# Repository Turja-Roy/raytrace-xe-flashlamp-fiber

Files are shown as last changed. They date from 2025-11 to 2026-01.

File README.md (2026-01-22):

# VUV Flashlamp-to-Fiber Coupling Optimization

A comprehensive ray tracing and optimization framework for designing two-lens optical systems that efficiently couple vacuum ultraviolet (VUV) light from xenon flashlamp sources into optical fibers.

## Table of Contents

- [Project Overview](#project-overview)
  - [Key Results](#key-results)
- [Features](#features)
  - [Six Optimization Algorithms](#six-optimization-algorithms)
  - [Multi-Objective Optimization](#multi-objective-optimization)
  - [Additional Capabilities](#additional-capabilities)
- [Performance](#performance)
  - [Vectorized Ray Tracing](#vectorized-ray-tracing)
  - [Benchmark Your System](#benchmark-your-system)
- [Database Storage](#database-storage)
  - [Two-Database Architecture](#two-database-architecture)
  - [Managing the Lens Database](#managing-the-lens-database)
  - [SQLite Backend for Results](#sqlite-backend-for-results)
- [Web Dashboard](#web-dashboard)
  - [Starting the Dashboard](#starting-the-dashboard)
  - [Features](#features-1)
  - [Usage Examples](#usage-examples)
  - [API Endpoints](#api-endpoints)
- [Installation](#installation)
  - [Requirements](#requirements)
  - [Quick Start](#quick-start)
- [Configuration Files](#configuration-files)
  - [Using Preset Profiles](#using-preset-profiles)
  - [Using Custom Configuration Files](#custom-configuration)
- [Usage Guide](#usage-guide)
  - [Basic Commands](#basic-commands)
  - [Command Reference](#command-reference)
- [File Structure](#file-structure)
- [Output Files](#output-files)
  - [Results CSVs](#results-csvs)
  - [Plot Files](#plot-files)
  - [Log Files](#log-files)
- [Physics and Implementation](#physics-and-implementation)
  - [Ray Tracing](#ray-tracing)
  - [Atmospheric Absorption](#atmospheric-absorption)
  - [Multi-Objective Optimization](#multi-objective-optimization-1)
- [Performance Recommendations](#performance-recommendations)
- [Example Workflows](#example-workflows)
- [Troubleshooting](#troubleshooting)
- [Technical Background](#technical-background)
  - [Research Context](#research-context)
  - [Physical Constants](#physical-constants)
  - [Optimization Implementation](#optimization-implementation)
<!-- - [Citation](#citation) -->
- [Author](#author)
- [Contributing](#contributing)

## Project Overview

This project addresses the challenge of efficiently collecting 220nm light from a xenon flashlamp arc source and coupling it into a small-core optical fiber. The system uses:

- **Source**: 60W Xenon flash lamp with 3mm diameter arc in water-cooled jacket
- **Geometry**: Cooling jacket with 26mm optical path length limits beam divergence to 22.85°
- **Target**: 1mm core optical fiber with NA=0.22 and acceptance angle of 24.8°
- **Approach**: Two-lens plano-convex system optimization via deterministic ray tracing
- **Physics**: Full geometric optics with atmospheric O₂ absorption modeling, geometric losses from cooling jacket vignetting (43% transmission)

> **📄 Technical Report**: For complete analysis, physical modeling details, and validated experimental design, see [`doc/technical_report.pdf`](doc/technical_report.pdf). The report documents the optimized LA4148+LA4022 configuration achieving 24% coupling in air and 26-27% in argon at 220nm.

### Key Results

- **Coupling Efficiency**: 24-27% achievable with optimized configurations under current geometry constraints (Air: 24%, Argon: 26-27% at 220nm)
- **System Length**: ~70mm for optimized configurations (e.g., LA4148+LA4022)
- **Atmospheric Impact**: 8-10% coupling improvement in argon vs. air due to eliminated O₂ absorption at 220nm
- **Medium Dependence**: Argon shows significantly better performance than air due to lack of UV absorption
- **Constraint Impact**: Cooling jacket geometry (lenses must be positioned ≥27mm from source) significantly constrains optimization space

#### Best Known Configuration

**Lens Pair**: LA4148 (f=50.2mm) + LA4022 (f=60mm)
- **Air Performance**: η = 0.24 (24%), L ≈ 70mm
- **Argon Performance**: η = 0.26-0.27 (26-27%), L ≈ 70mm
- **Positions**: z₁ ≈ 27mm (cooling jacket constraint), z₂ ≈ 34mm
- **Physical Implementation**: ThorLabs SM1 optomechanics (see `Assembly/` directory)

This configuration is validated through multiple optimization methods and documented in `doc/technical_report.pdf`.

## Features

### Seven Optimization Algorithms

| Method | Speed | Convergence | Best For |
|---|---|---|---|
| **Paraxial** ⚡⚡ | ~7ms | Fast screening | **Ultra-fast initial screening of thousands of combinations** |
| **Powell** ⚡ | ~0.1-0.2s | Good | **Quick optimization, everyday use** |
| **Nelder-Mead** ⚡ | ~0.1-0.2s | Good | **Fast local search** |
| Grid Search | ~0.2-0.3s | Systematic | Baseline comparison, small grids |
| Differential Evolution | ~1-2s | Excellent | Thorough global search when time permits |
| Bayesian | ~2-3s | Excellent | Sample-efficient exploration |
| Dual Annealing | ~4-5s | Excellent | Escaping local minima |

*Timings are per lens pair with 1000 rays using vectorized tracing on typical hardware. Paraxial uses analytical approximation (no ray tracing).*

**⚠️ Important Note on Paraxial Approximation**: The paraxial screening mode uses thin/thick lens equations with ABCD matrix propagation for ultra-fast evaluation (~20,503 combinations in ~3 minutes). However, it has known limitations:
- **Grid search limitations**: Uses coarse 5×5×5 grid (125 samples per pair) which may miss optimal configurations
- **Spacing assumptions**: Assumes lenses should be separated by ≥0.5× focal length, but optimal configurations may have much closer spacing
- **Best use case**: Initial screening to identify promising candidates, followed by full ray-trace optimization
- **Not a replacement**: Should be used to guide full optimization, not replace it

### Multi-Objective Optimization

Balance coupling efficiency against system compactness using the alpha parameter:

```
objective = α × (1 - coupling) + (1 - α) × (normalized_length)
```

- **α = 0.9**: Maximize coupling (90% weight) - laboratory setups
- **α = 0.7**: Balanced (default) - general purpose
- **α = 0.5**: Equal priority - compact designs

### Additional Capabilities

- **Paraxial Approximation**: Ultra-fast screening of all 20,503 lens combinations in ~3 minutes using analytical approximations
- **Tolerance Analysis**: Assess manufacturing sensitivity to longitudinal displacements (single-pair and batch modes)
- **Wavelength Analysis**: Study coupling efficiency across 180-300nm range
- **Web Dashboard**: Interactive browser-based results viewer with filtering and plotting
- **Medium Selection**: Air, argon, or helium propagation
- **Resume Support**: Automatic checkpoint/resume for interrupted batch runs
- **Rich Visualization**: Ray trace diagrams, spot diagrams, wavelength plots, tolerance curves
- **Batch Processing**: Automatic splitting and parallel processing of large lens catalogs
- **Dual Database Architecture**: Separate lens catalog (202 lenses) and optimization results databases

## Performance

### Vectorized Ray Tracing

The codebase uses **vectorized NumPy operations** for ray tracing, achieving **10-15x speedup** over serial implementations:

- **1,000 rays**: ~12ms (vectorized) vs ~120ms (serial) ⚡
- **10,000 rays**: ~19ms (vectorized) vs ~287ms (serial) ⚡

All optimization algorithms automatically use vectorized tracing. To disable (for debugging):

```yaml
# In your config file
rays:
  use_vectorized: false  # Default: true
```

**Implementation details**:
- Batch processing of all rays simultaneously using NumPy broadcasting
- Vectorized ray-sphere intersections, refraction calculations, and transmission factors
- Boolean masks to track ray success/failure through optical pipeline
- Located in `scripts/raytrace_helpers_vectorized.py`

### Benchmark Your System

```bash
python test_vectorization.py --rays 5000 --trials 5
```

Expected output:
```
Serial time:     0.045 ± 0.010 s
Vectorized time: 0.003 ± 0.001 s
Speedup:         13.9x
```

## Database Storage

The system uses two SQLite databases:
- **Lens catalog** (`data/lenses.db`): 202 lenses from ThorLabs and Edmund Optics
- **Optimization results** (`results/optimization.db`): Stores run metadata and results

### Managing Lenses

```bash
# Import lenses from CSV
python raytrace.py import-lenses

# List available lenses
python raytrace.py list-lenses --use-database

# Add new lenses
python -m scripts.add_lenses_from_csv new_lenses.csv --format thorlabs
```

### Querying Results

Enable database storage in `configs/default.yaml`:
```yaml
database:
  enabled: true
  path: ./results/optimization.db
```

Common queries:
```bash
# Show all runs
python -m scripts.db_query list-runs

# Find best results
python -m scripts.db_query best --limit 20 --min-coupling 0.20

# Export specific run
python -m scripts.db_query export-run 2025-10-24_coupling_0_21_air output.csv
```

## Web Dashboard

Interactive browser-based interface for viewing, filtering, and analyzing optimization results.

### Starting the Dashboard

```bash
# Auto-detect database or use CSV files
python raytrace.py dashboard

# Custom port
python raytrace.py dashboard --port 8080

# Specify database file
python raytrace.py dashboard --db results/integration_test.db

# Using config file
python raytrace.py dashboard --config my_config.yaml

# Config with CLI override
python raytrace.py dashboard --config my_config.yaml --port 5000
```

**Config file example** (`my_config.yaml`):
```yaml
dashboard:
  port: 8080
  db_path: results/optimization.db
  auto_open: false  # Future feature
```

The dashboard will start a local web server and display:
```
Dashboard running at http://localhost:5000
Press Ctrl+C to stop
```

Open the URL in your browser to access the interface.

### Features

**Statistics Overview**:
- Total optimization results
- Number of runs
- Best coupling efficiency achieved
- Average coupling across all results

**Interactive Filtering**:
- Filter by coupling efficiency range (min/max)
- Filter by medium (air, argon, helium)
- Filter by specific lens pairs
- Export filtered results as CSV

**Data Visualization**:
- Results table with sorting (click column headers)
- Coupling efficiency distribution histogram
- Lens pair comparison plots (compare different optimization methods)

**Data Sources**:
- Automatically reads from SQLite database if available
- Falls back to CSV files in `results/` directory
- Scans all subdirectories for optimization results
- Skips tolerance and wavelength analysis files

### Usage Examples

```bash
# View results from a specific database
python raytrace.py dashboard --db results/optimization.db

# Run on a different port (e.g., if 5000 is in use)
python raytrace.py dashboard --port 8888

# View CSV results without database
python raytrace.py dashboard  # Auto-detects and loads CSV files
```

## Installation

### Requirements

- Python 3.7+
- Required packages:
  ```bash
  pip install numpy scipy pandas matplotlib tqdm regex flask
  ```
- Optional (for Bayesian optimization):
  ```bash
  pip install scikit-optimize
  ```
- Optional (for web dashboard):
  ```bash
  pip install flask
  ```
  *Note: Flask is included in the required packages above*

### Quick Start

```bash
git clone <repository>
cd raytrace-xe-flashlamp-fiber
python raytrace.py particular LA4001 LA4647 --opt powell
```

## Configuration Files

All modes support YAML configuration files for parameter management. CLI arguments override config values.

### Using Preset Profiles

```bash
# Quick test (100 rays, Powell, fast)
python raytrace.py particular LA4001 LA4647 --profile quick_test

# Argon batch (1000 rays, differential evolution)
python raytrace.py combine --profile argon_batch

# Tolerance test (5000 rays, 41 samples, ±1mm)
python raytrace.py tolerance LA4001 LA4647 --profile tolerance_test
```

Available profiles in `configs/`: `quick_test`, `argon_batch`, `wavelength_study`, `tolerance_test`, `integration_test`

### Custom Configuration

Create `my_config.yaml`:

```yaml
rays:
  n_rays: 1500

medium:
  type: argon

optimization:
  method: powell

analyze:
  coupling_threshold: 0.22
  methods: [differential_evolution, powell]
```

Use it:
```bash
python raytrace.py particular LA4001 LA4647 --config my_config.yaml

# CLI overrides config
python raytrace.py particular LA4001 LA4647 --config my_config.yaml --medium air
```

See `configs/default.yaml` for all available options.

## Usage Guide

### Basic Commands

#### Screen All Lens Combinations with Paraxial Approximation (Ultra-Fast)

```bash
# Screen all 20,503 combinations in ~3 minutes (requires --use-database)
python raytrace.py paraxial --use-database --medium argon

# Results are filtered to coupling ≥ 1% and sorted by predicted coupling
# Outputs CSV with top candidates for full ray-trace optimization
```

**Note**: Paraxial approximation provides fast screening but has limitations (see warnings in Features section). Use results to guide full optimization, not as final values.

**Recommended workflow:**
```bash
# 1. Fast paraxial screening
python raytrace.py paraxial --use-database --medium argon

# 2. Review top candidates
head -20 results/paraxial_2025-11-19_argon/paraxial_results_2025-11-19.csv

# 3. Full optimization on top candidates
python raytrace.py particular 84-281 89-414 --opt differential_evolution --medium argon
```

#### Optimize a Specific Lens Pair (Recommended Starting Point)

```bash
# Fast optimization with Powell's method (recommended)
python raytrace.py particular LA4001 LA4647 --opt powell

# Thorough optimization with differential evolution (slower but more thorough)
python raytrace.py particular LA4001 LA4647 --opt differential_evolution

# Try in argon (no UV absorption)
python raytrace.py particular LA4001 LA4647 --opt powell --medium argon
```

#### Optimize All Combinations

```bash
# Strategic scan with pre-selected L1/L2 candidates (924 combinations, recommended)
python raytrace.py select --opt powell

# Exhaustive scan of all possible combinations (24,336 combinations)
python raytrace.py combine --opt powell

# Prioritize coupling efficiency (90% weight)
python raytrace.py select --opt powell --alpha 0.9

# Prioritize compact systems (50/50 weight)
python raytrace.py select --opt powell --alpha 0.5
```

**Select vs Combine modes:**
- **select**: Tests 21 L1 candidates × 44 L2 candidates = 924 strategically chosen lens pairs
- **combine**: Tests all 156 lenses × 156 lenses = 24,336 possible combinations (26× more)
- **Recommendation**: Use `select` for efficient exploration; use `combine` only when exhaustive search is needed

#### Compare All Methods

```bash
# Test all 6 optimization methods on a single lens pair
python raytrace.py compare LA4001 LA4647
```

This runs all available methods and reports:
- Coupling efficiency achieved
- Total system length
- Computation time
- Best method recommendation

#### Resume Interrupted Batch Runs

```bash
# Resume from checkpoint
python raytrace.py combine --opt powell continue 2025-10-14
```

#### Analyze High-Coupling Results

Re-optimize promising results with multiple methods to find absolute best configurations.

```bash
# CLI-only usage
python raytrace.py analyze \
  --results-file results/2025-10-17/results_combine_*.csv \
  --coupling-threshold 0.20

# Using config file to specify methods and parameters
python raytrace.py analyze \
  --config my_config.yaml \
  --results-file results/2025-10-17/results_combine_*.csv

# Config with CLI override
python raytrace.py analyze \
  --config my_config.yaml \
  --results-file results/2025-10-17/results_combine_*.csv \
  --coupling-threshold 0.18 \
  --n-rays 2000
```

**Config file example** (`my_config.yaml`):
```yaml
analyze:
  n_rays: 1000
  coupling_threshold: 0.22
  methods:
    - differential_evolution
    - dual_annealing
    - powell
```

The `methods` list controls which optimizers to test on each lens pair. Results are saved separately for each method and combined into a single best-of-all file.

#### Wavelength Dependence Analysis

Study how coupling varies with wavelength.

```bash
# CLI-only usage
python raytrace.py wavelength-analyze \
  --results-file results/2025-10-17/36-681+LA4647.csv \
  --wl-start 180 --wl-end 300 --wl-step 10

# Using config file
python raytrace.py wavelength-analyze \
  --config my_config.yaml \
  --results-file results/2025-10-17/36-681+LA4647.csv

# Config with CLI override for wavelength range
python raytrace.py wavelength-analyze \
  --config my_config.yaml \
  --results-file results/2025-10-17/36-681+LA4647.csv \
  --wl-start 190 --wl-end 210 --wl-step 2
```

**Config file example** (`my_config.yaml`):
```yaml
wavelength:
  wl_start: 180
  wl_end: 300
  wl_step: 10
  n_rays: 2000
  methods:
    - differential_evolution
    - powell
```

The `methods` list controls which optimizers calibrate the geometry at 220nm before wavelength sweeping.

**Plotting results:**
```bash
# Generate plots from wavelength analysis
python raytrace.py wavelength-analyze-plot \
  --results-dir results/wavelength_analyze_2025-10-18

# With polynomial curve fitting
python raytrace.py wavelength-analyze-plot \
  --results-dir results/wavelength_analyze_2025-10-18 \
  --fit polynomial

# Aggregated plots with error bars
python raytrace.py wavelength-analyze-plot \
  --results-dir results/wavelength_analyze_2025-10-18 \
  --aggregate
```

#### Tolerance Analysis

Assess manufacturing sensitivity by analyzing how coupling efficiency varies with small displacements in lens positions.

##### Single Lens Pair Mode

```bash
# Analyze tolerance for a specific lens pair
python raytrace.py tolerance LA4001 LA4647 --opt powell

# Use high-resolution tolerance profile from config
python raytrace.py tolerance LA4001 LA4647 --profile tolerance_test

# Custom tolerance parameters
python raytrace.py tolerance LA4001 LA4647 \
  --z-range 1.0 \
  --n-samples 41 \
  --n-rays 5000

# Test in argon environment
python raytrace.py tolerance LA4001 LA4647 --opt powell --medium argon
```

##### Batch Mode

Analyze tolerance for multiple lens pairs from optimization results:

```bash
# Batch tolerance analysis on high-coupling results
python raytrace.py tolerance \
  --results-file results/2025-11-07_combine_powell_argon/batch_combine_1.csv \
  --coupling-threshold 0.35 \
  --z-range 1.0 \
  --n-samples 41 \
  --n-rays 5000 \
  --medium argon \
  --use-database

# Use config file with defaults (results_file and coupling_threshold from config)
python raytrace.py tolerance --profile tolerance_test --use-database

# Or override specific config values via CLI
python raytrace.py tolerance \
  --profile tolerance_test \
  --coupling-threshold 0.35 \
  --use-database
```

**Batch mode benefits:**
- Test tolerance on multiple optimized configurations at once
- Compare tolerance characteristics across different lens pairs
- Identify most manufacturable designs (highest tolerance to misalignment)
- Uses pre-optimized positions from results file (no re-optimization needed)

**What it does**:
- First optimizes the lens pair to find best configuration
- Systematically perturbs each lens position (z_l1, z_l2) independently
- Measures coupling efficiency at each position
- Generates tolerance curves showing sensitivity to misalignment

**Output files (single-pair mode)**:
- `tolerance_L1_<lens1>+<lens2>.csv` - L1 position sweep data
- `tolerance_L2_<lens1>+<lens2>.csv` - L2 position sweep data
- `tolerance_summary_<lens1>+<lens2>.csv` - Summary statistics
- `tolerance_<lens1>+<lens2>.png` - Tolerance curve plot

**Output files (batch mode)**:
- `tolerance_L1_<lens1>+<lens2>.csv` - L1 sweep data for each pair
- `tolerance_L2_<lens1>+<lens2>.csv` - L2 sweep data for each pair
- `tolerance_summary_<lens1>+<lens2>.csv` - Individual pair summary
- `tolerance_batch_summary.csv` - Comparison across all pairs
- `tolerance_batch_comparison.png` - Bar chart comparing all configurations

**Configuration options** (in YAML config files):
```yaml
tolerance:
  z_range_mm: 1.0      # ±1.0mm range around optimal position
  n_samples: 41        # Number of positions to test (41 = 0.05mm steps)
  n_rays: 5000         # Rays per position (higher = more accurate)

batch_tolerance:
  results_file: results/combine_*/batch_combine_1.csv  # Results CSV for batch mode
  coupling_threshold: 0.35    # Minimum coupling to include in batch analysis
```

**Interpreting results**:
- Steep slopes indicate high sensitivity to that lens position
- Flat regions indicate tolerance to small displacements
- Asymmetric curves reveal directional sensitivity
- Use results to set manufacturing tolerances

**Example workflow**:
```bash
# 1. Find best configuration
python raytrace.py particular LA4001 LA4647 --opt differential_evolution

# 2. Analyze tolerance with high resolution
python raytrace.py tolerance LA4001 LA4647 --profile tolerance_test

# 3. Review tolerance curves
ls plots/*tolerance*/tolerance_LA4001+LA4647.png

# 4. Check numerical results
cat results/*tolerance*/tolerance_summary_LA4001+LA4647.csv
```

### Command Reference

```
Commands:
  particular <lens1> <lens2>    Optimize specific lens pair
  compare <lens1> <lens2>       Compare all optimization methods
  select                        Optimize L1×L2 candidate combinations (924 pairs, recommended)
  combine                       Optimize all lens combinations (24,336 pairs, exhaustive)
  paraxial                      Ultra-fast screening of all 20,503 combinations using analytical approximation (~3min)
  analyze                       Re-analyze high-coupling results
  wavelength-analyze            Study wavelength dependence
  wavelength-analyze-plot       Create plots from wavelength data
  tolerance <lens1> <lens2>     Analyze manufacturing tolerance sensitivity
  dashboard                     Start interactive web dashboard
  import-lenses                 Import lenses from CSV files into database
  list-lenses                   List available lenses from database or CSV

Options:
  --opt <method>                Optimization method (default: powell)
                                Options: powell, nelder_mead, grid_search,
                                         differential_evolution, bayesian,
                                         dual_annealing
  --alpha <0-1>                 Coupling vs. length trade-off (default: 0.7)
  --medium <type>               Propagation medium (default: air)
                                Options: air, argon, helium
  --n-rays <count>              Number of rays per trace (default: 1000)
  --wl-start <nm>               Wavelength analysis start (default: 180)
  --wl-end <nm>                 Wavelength analysis end (default: 300)
  --wl-step <nm>                Wavelength analysis step (default: 10)
  --z-range <mm>                Tolerance analysis range (default: 0.5)
  --n-samples <count>           Tolerance analysis samples (default: 21)
  --coupling-threshold <value>  Minimum coupling for analyze mode
  --results-file <path>         Input CSV file for analyze/wavelength modes
  --results-dir <path>          Results directory for plotting
  --fit <type>                  Curve fit type: polynomial, spline
  --aggregate                   Generate aggregated plots with error bars
  --port <number>               Dashboard port (default: 5000)
  --db <path>                   Database file for dashboard
  --profile <name>              Use preset configuration profile
  --config <path>               Use custom YAML configuration file
  continue                      Resume incomplete batch run
  <YYYY-MM-DD>                  Specify run date for continue mode
```

## File Structure

```
raytrace-xe-flashlamp-fiber/
├── raytrace.py                    # Main entry point
│
├── scripts/
│   ├── optimization/              # Optimization algorithms
│   │   ├── __init__.py
│   │   ├── powell.py              # Powell's method (fast)
│   │   ├── nelder_mead.py         # Nelder-Mead simplex (fast)
│   │   ├── grid_search.py         # Systematic grid search
│   │   ├── differential_evolution.py  # Global optimizer (thorough)
│   │   ├── bayesian.py            # Bayesian optimization
│   │   ├── dual_annealing.py      # Simulated annealing
│   │   ├── optimization_runner.py # Unified interface
│   │   └── fiber_position_optimizer.py  # Fiber position optimization helper
│   │
│   ├── analysis.py                # Analysis and wavelength studies
│   ├── Aspheric.py                # Aspheric lens class
│   ├── BiConvex.py                # Bi-convex lens class
│   ├── calcs.py                   # Physics calculations (refraction, absorption)
│   ├── cli.py                     # Command-line interface
│   ├── config_loader.py           # YAML configuration file handler
│   ├── consts.py                  # Physical constants and system parameters
│   ├── data_io.py                 # File I/O and result management
│   ├── database.py                # SQLite database backend (optimization results)
│   ├── db_query.py                # Database query CLI
│   ├── hitran_data.py             # HITRAN absorption data handling
│   ├── lens_database.py           # Lens catalog database management
│   ├── lens_factory.py            # Lens object factory
│   ├── paraxial_approximation.py  # Ultra-fast paraxial screening (~7ms/pair)
│   ├── PlanoConvex.py             # Plano-convex lens class
│   ├── raytrace_helpers.py        # Core ray tracing functions
│   ├── raytrace_helpers_vectorized.py  # Vectorized ray tracing (10-15x faster)
│   ├── runner.py                  # Batch processing and continuation
│   ├── tolerance_analysis.py      # Manufacturing tolerance testing
│   ├── visualizers.py             # Plotting and visualization
│   └── web_dashboard.py           # Flask-based interactive web dashboard
│
├── configs/                       # YAML configuration files
│   ├── default.yaml               # Default parameters
│   ├── quick_test.yaml            # Fast testing profile
│   ├── argon_batch.yaml           # Argon medium batch profile
│   ├── wavelength_study.yaml      # Wavelength analysis profile
│   ├── tolerance_test.yaml        # High-resolution tolerance profile
│   └── integration_test.yaml      # Database integration testing
│
├── data/                          # Lens catalogs
│   ├── lenses.db                  # SQLite lens catalog database (202 lenses)
│   ├── Combined_Lenses.csv        # Full lens catalog CSV (legacy, 156 lenses)
│   ├── l1_candidates.csv          # Candidate L1 lenses
│   ├── l1_candidates_ext.csv      # Extended L1 candidates
│   ├── l2_candidates.csv          # Candidate L2 lenses
│   ├── l2_candidates_ext.csv      # Extended L2 candidates
│   └── *.csv, *.xlsx              # Vendor lens data (ThorLabs, Edmund Optics)
│
├── results/                       # Output directory
│   ├── <run_id>/                  # Results organized by run ID
│   │   ├── batch_*.csv            # Intermediate batch results
│   │   ├── results_*.csv          # Final combined results
│   │   ├── tolerance_*.csv        # Tolerance analysis data
│   │   └── temp_*.json            # Checkpoint files
│   └── *.db                       # SQLite database files
│
├── plots/                         # Generated plots
│   └── <run_id>/
│       ├── C-<coupling>_L1-*_L2-*.png      # Ray trace diagrams
│       ├── spot_*.png                       # Spot diagrams
│       ├── tolerance_*.png                  # Tolerance curves
│       └── wavelength_analyze_*/            # Wavelength analysis plots
│
├── logs/                          # Execution logs
│   └── *.log                      # Detailed execution logs
│
├── Assembly/                      # CAD models and mechanical design
│   ├── Assembly.FCStd             # FreeCAD assembly file (LA4148+LA4022)
│   ├── List.md                    # Parts list (ThorLabs SM1 components)
│   └── *.step                     # Individual component STEP files
│
└── doc/                           # Documentation
    ├── technical_report.pdf       # Full technical report
    ├── images/                    # Figures and plots for report
    └── *.tex, *.bib               # LaTeX source files
```

## Output Files

### Results CSVs

All optimization results are saved as CSV files with columns:

- `lens1`, `lens2`: Lens identifiers
- `f1_mm`, `f2_mm`: Focal lengths (mm)
- `z_l1`, `z_l2`, `z_fiber`: Positions along optical axis (mm)
- `total_len_mm`: Total system length (mm)
- `coupling`: Coupling efficiency (0-1)

Example: `results/2025-10-18_combine_powell_air/results_combine_2025-10-18.csv`

### Plot Files

#### Ray Trace Diagrams
Shows full ray paths through the optical system with lens positions and fiber location.

Filename format: `C-<coupling>_L1-<lens1>_L2-<lens2>.png`

#### Spot Diagrams
Shows ray impact positions at the fiber face, indicating coupling quality.

Filename format: `spot_C-<coupling>_L1-<lens1>_L2-<lens2>.png`

#### Wavelength Analysis Plots
- Per-lens plots: Coupling vs. wavelength for each lens combination
- Per-method plots: Comparing all lens pairs for each optimization method
- Aggregated plots: Mean curves with error bars across multiple runs

### Log Files

Detailed execution logs including:
- Timestamp for each optimization
- Method being used
- Coupling efficiency and system length
- Computation time
- Error messages and warnings

Example: `logs/2025-10-18_combine_powell_air.log`

## Physics and Implementation

Uses deterministic ray tracing with atmospheric absorption modeling (O₂ absorption in air). Multi-objective optimization balances coupling efficiency against system length using the `alpha` parameter. See `doc/technical_report.pdf` for detailed physics and implementation.

## Performance Recommendations

### For Ultra-Fast Initial Screening
**Use Paraxial Approximation** - Screen all 20,503 combinations in ~3 minutes:
```bash
python raytrace.py paraxial --use-database --medium argon
# Then full ray-trace on top candidates
```

### For Everyday Use
**Use Powell's method** - Fast and reliable:
```bash
python raytrace.py combine --opt powell
```

### For Best Possible Results
**Use Differential Evolution** - Slower but more thorough:
```bash
python raytrace.py combine --opt differential_evolution
```

### For Method Comparison
**Use compare mode** - Test all methods on a sample:
```bash
python raytrace.py compare LA4001 LA4647
```

### For Large Catalogs (Recommended Workflow)
**Multi-stage approach for best results**:
```bash
# Stage 1: Ultra-fast paraxial screening (~3 min for all 20,503 pairs)
python raytrace.py paraxial --use-database --medium argon

# Stage 2: Fast ray-trace on top 100 from paraxial (~10 min with Powell)
# Extract top lens pairs from paraxial results, then:
python raytrace.py particular <lens1> <lens2> --opt powell --medium argon

# Stage 3: Thorough optimization on top 20 (~3-5 min with DE)
python raytrace.py particular <lens1> <lens2> --opt differential_evolution --medium argon

# Total time: ~15-20 minutes vs. ~8 hours for full DE on all pairs
```

### Alternative: Traditional Approach (No Paraxial)
**Start with Powell, verify with DE**:
```bash
# 1. Fast scan with Powell (~40 min for all 24,336 pairs)
python raytrace.py combine --opt powell

# 2. Re-optimize top candidates with differential evolution
python raytrace.py analyze \
  --results-file results/2025-10-18/results_*.csv \
  --coupling-threshold 0.20 \
  --opt differential_evolution
```

## Example Workflows

### Workflow 1: Ultra-Fast Screening with Paraxial Approximation

**Best for**: Quickly identifying promising lens pairs from full catalog

```bash
# Step 1: Fast paraxial screening of all 20,503 combinations (~3 minutes)
python raytrace.py paraxial --use-database --medium argon

# Step 2: Review top candidates
head -30 results/paraxial_2025-11-19_argon/paraxial_results_2025-11-19.csv

# Step 3: Full ray-trace optimization on top 10 candidates
# Example: Top result is 84-281 + 89-414 with predicted 35.5% coupling
python raytrace.py particular 84-281 89-414 --opt differential_evolution --medium argon

# Step 4: Batch optimize multiple promising pairs
for pair in "84-281 89-414" "48-278 LA4194" "84-282 89-411"; do
    python raytrace.py particular $pair --opt differential_evolution --medium argon
done

# Step 5: Compare results
grep "Coupling=" logs/particular_*_differential_evolution_argon.log

# Step 6: Tolerance analysis on best performer
python raytrace.py tolerance 84-281 89-414 --profile tolerance_test --medium argon
```

**Important Notes**:
- Paraxial provides screening only - actual coupling may differ significantly
- Some lens pairs may perform better than paraxial predicts (e.g., if optimal spacing is closer than paraxial assumes)
- Always validate with full ray tracing before finalizing design

### Workflow 2: Find Best Lens Pair for Maximum Coupling

```bash
# Step 1: Quick scan prioritizing coupling
python raytrace.py combine --opt powell --alpha 0.9

# Step 2: Re-optimize top candidates thoroughly
python raytrace.py analyze \
  --results-file results/2025-10-18_combine_powell_air/results_combine_2025-10-18.csv \
  --coupling-threshold 0.22

# Step 3: View results interactively
python raytrace.py dashboard
```

### Workflow 3: Manufacturing Tolerance Assessment

```bash
# Step 1: Optimize a promising lens pair
python raytrace.py particular LA4001 LA4647 --opt differential_evolution

# Step 2: Run high-resolution tolerance analysis
python raytrace.py tolerance LA4001 LA4647 --profile tolerance_test

# Step 3: View tolerance curves
ls plots/2025-10-24_None_powell_air/tolerance_LA4001+LA4647.png

# Step 4: Check tolerance summary statistics
cat results/2025-10-24_None_powell_air/tolerance_summary_LA4001+LA4647.csv

# Step 5: Compare tolerances in different media
python raytrace.py tolerance LA4001 LA4647 --opt powell --medium argon \
  --z-range 1.0 --n-samples 41
```

### Workflow 4: Interactive Results Analysis with Dashboard

```bash
# Step 1: Run batch optimization with database enabled
# (Ensure database.enabled: true in configs/default.yaml)
python raytrace.py select --opt powell --alpha 0.9

# Step 2: Start the dashboard with config
python raytrace.py dashboard --config dashboard_config.yaml

# Step 3: Open browser to http://localhost:8080 (or configured port)
# - Filter results by coupling > 0.22
# - View coupling distribution histogram
# - Compare different lens pairs
# - Export filtered results as CSV

# Alternative: Use CSV files directly (no database)
python raytrace.py dashboard  # Auto-detects CSV files

# Step 4: Export high-performing results via API
curl "http://localhost:8080/api/export?min_coupling=0.22" -o best_results.csv
```

**dashboard_config.yaml:**
```yaml
dashboard:
  port: 8080
  db_path: results/optimization.db
```

## Troubleshooting

### Slow Performance

**Problem**: Optimization takes too long  
**Solutions**:
- Use Powell or Nelder-Mead instead of Differential Evolution
- Reduce number of rays: `--n-rays 500`
- Process specific lens pairs instead of full catalog

### Poor Coupling Results

**Problem**: Low coupling efficiency  
**Solutions**:
- Try different optimization method: `--opt differential_evolution`
- Increase alpha to prioritize coupling: `--alpha 0.9`
- Verify lens data in `data/Combined_Lenses.csv`
- Check if lenses are physically compatible

### Import Errors

**Problem**: `ModuleNotFoundError: No module named 'skopt'`  
**Solution**: Install scikit-optimize or use different method:
```bash
pip install scikit-optimize
# OR
python raytrace.py combine --opt powell
```

### Interrupted Batch Runs

**Problem**: Run stopped midway through catalog  
**Solution**: Resume from checkpoint:
```bash
python raytrace.py combine --opt powell continue 2025-10-18
```

### Memory Issues

**Problem**: Out of memory with large catalogs  
**Solutions**:
- Batch processing is automatic for >100 combinations
- Reduce rays per trace: `--n-rays 500`
- Process smaller subsets using `particular` mode

### Paraxial Results Don't Match Full Ray Tracing

**Problem**: Lens pair performs well in full ray tracing but missing or poor in paraxial results  
**Root Causes**:
1. **Grid search limitations**: Paraxial uses 5×5×5 coarse grid (125 samples) which may miss optimal positions
2. **Conservative spacing assumptions**: Assumes z_l2 ≥ z_l1 + tc + 0.5×f1, but optimal may be much closer
3. **Same-lens pairs**: May require tighter spacing than paraxial grid searches

**Example**: Some lens pairs like 48-274 + 48-274 perform well in full ray tracing (z_l1=27mm, z_l2=33mm) but paraxial predicts <1% because the grid doesn't search close lens spacing (e.g., z_l2 < 58mm). The current best configuration LA4148+LA4022 achieves 24-27% coupling and was identified through systematic full ray-trace optimization.

**Solutions**:
- Use paraxial for initial screening only, not final values
- Always validate promising pairs with full ray-trace optimization
- For specific pairs of interest, run full optimization directly with `particular` mode
- Consider paraxial results as conservative lower bounds

**Recommended workflow**: Paraxial screening → Full optimization of top 20-50 candidates → Tolerance analysis of best results

## Technical Background

This project optimizes two-lens optical systems for coupling 220nm VUV light from xenon flashlamps into optical fibers. For research context, physical constants, optimization algorithms, and implementation details, see `doc/technical_report.pdf`.

<!-- ## Citation -->
<!---->
<!-- If you use this code in your research, please cite: -->
<!---->
<!-- ``` -->
<!-- Turja Roy, "Optimization of Two-Lens Coupling Systems for VUV Flashlamp  -->
<!-- to Fiber Applications Using Ray Tracing and Multi-Algorithm Comparison", -->
<!-- University of Texas at Arlington (2025) -->
<!-- ``` -->
<!---->
<!-- Technical report: `doc/technical_report.pdf` -->

## Author

**Turja Roy**  
Department of Physics  
University of Texas at Arlington

## Contributing

For questions, issues, or contributions, please contact the author or open an issue in the repository.

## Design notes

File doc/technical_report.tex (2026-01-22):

\input{preamble.tex}
\usepackage{bm}

\title{\large\bfseries
    A Modular Ray Tracing Framework for Optimizing VUV Flashlamp-to-Fiber Coupling Systems
}

\author{Turja Roy, Dr. Jonathan Abraham Asaadi, Dr. Varghese Anto Chirayath}
\affil{Department of Physics, University of Texas at Arlington, Arlington, TX 76019, USA}
\date{}

\begin{document}

\twocolumn[
\begin{@twocolumnfalse}
    \maketitle

    \begin{abstract}
        A comprehensive ray tracing methodology is presented for optimizing two-lens coupling systems for vacuum ultraviolet (VUV) flashlamp-to-fiber applications with realistic experimental constraints. The system couples 220 nm light from a Hamamatsu L7685 60W xenon flashlamp (3 mm arc) with E6611 cooling jacket into a 1 mm fiber core (NA = 0.22). The cooling jacket imposes critical geometric constraints: lens positioning constrained to z $\geq$ 27 mm and angular acceptance limited to 22.85$^\circ$, introducing 43\% geometric vignetting loss. Six optimization algorithms---grid search, Powell's method, differential evolution, Nelder-Mead simplex, dual annealing, and Bayesian optimization---are systematically compared using deterministic ray tracing with atmospheric absorption modeling. Systematic analysis identifies optimal configurations achieving coupling efficiencies up to 0.27 (argon) and 0.24 (air) at 220 nm, representing realistic performance under cooling jacket constraints. Powell's method and Nelder-Mead emerge as recommended algorithms for routine optimization, providing rapid convergence (~0.5--1 s per lens pair) and reliable performance. Combined atmospheric oxygen absorption and extended path lengths (optical system $L \approx$ 70 mm) create measurable medium-dependent effects at 220 nm: systematic comparison reveals 8--10\% coupling improvement in argon versus air for the LA4148+LA4022 configuration, closely matching the predicted 8.1\% atmospheric absorption loss and validating the attenuation model. This indicates air propagation is viable when the performance penalty is acceptable, while argon maximizes coupling. Wavelength dependence analysis (150--300 nm) establishes chromatic performance characteristics and validates wavelength-dependent material modeling. The framework provides both a practical design tool incorporating realistic experimental constraints and methodological insights for non-convex optical optimization problems.
    \end{abstract}
    \vspace{0.5cm}
\end{@twocolumnfalse}
]

\section{Introduction}

Efficient coupling of vacuum ultraviolet light from incoherent sources into optical fibers presents significant challenges due to the inherent divergence of arc lamp sources and the limited acceptance angles of fibers \cite{hecht2017}. The Hamamatsu L7685 60W xenon flash lamp provides a compact broadband source (190--2000 nm) suitable for liquid argon purity monitoring applications in the VUV/DUV range. This work focuses on optimizing coupling at the design wavelength of 220 nm, where fiber-optic delivery enables remote sensing and flexible optical system configurations in cryogenic environments.

The design of compact coupling optics requires balancing multiple objectives: maximizing coupling efficiency, minimizing physical length, and maintaining practical manufacturability with commercially available optical components. Traditional lens design approaches often rely on paraxial approximations or specialized optical design software \cite{greivenkamp2004}. However, the large numerical aperture and wide divergence angles in Xe flashlamp systems necessitate full ray tracing to accurately predict system performance.

In this work, a stratified ray tracing framework is developed that incorporates realistic source geometry, lens specifications, fiber acceptance criteria, and atmospheric absorption effects (O$_2$, N$_2$, and H$_2$O). The design problem is formulated as a multi-objective optimization task, and six distinct optimization algorithms are systematically compared to identify lens positioning that maximizes performance. This approach provides both a practical design tool and insights into the efficacy of various optimization strategies for optical systems with complex, non-convex objective functions characterized by multiple local optima and discrete ray-counting mechanics that preclude
 analytical gradient computation.

\section{System Description}

\subsection{Optical Configuration}

The optical system comprises a Hamamatsu L7685 60W xenon flash lamp \cite{hamamatsu} with Hamamatsu E6611 cooling jacket, two fused silica lenses, and a multi-mode optical fiber \cite{accuglass} arranged along a common optical axis. The lamp emits broadband radiation (190--2000 nm) from a compact 3.0 mm diameter arc; this work analyzes coupling performance at $\lambda =$ 150--300 nm. 

The lamp assembly includes a protective Single Crystal Sapphire Glass window (14.3 mm diameter) positioned 8.7 mm from the arc. Critically, the Hamamatsu E6611 cooling jacket surrounds the lamp housing and constrains the optical aperture through its M23 threaded exit port (inner diameter 23 mm) located approximately 26 mm from the arc center. This cooling jacket imposes both geometric constraints on lens positioning and vignetting losses on the emitted light, as detailed in Section 2.2. The two-lens relay system is positioned after the cooling jacket exit to collect and refocus the divergent light into the fiber.

% FIGURE 1: Lamp and Cooling Jacket Dimensional Outline
\begin{figure}[htpb]
    \centering
    \begin{subfigure}{0.45\textwidth}
        \centering
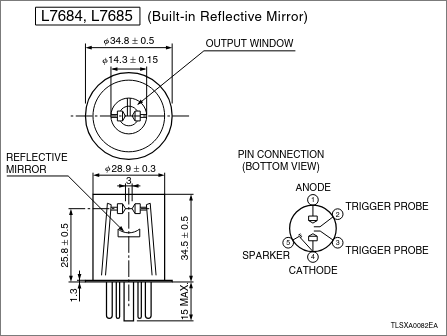
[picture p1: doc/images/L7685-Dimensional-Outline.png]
        
        \caption{}
    \end{subfigure}
    \begin{subfigure}{0.45\textwidth}
        \centering
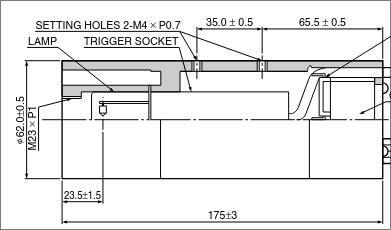
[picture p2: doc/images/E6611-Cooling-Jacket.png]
        
        \caption{}
    \end{subfigure}
    \caption{Dimensional Outline of (a) Hamamatsu L7685 Xenon Flash Lamp and (b) Hamamatsu E6611 Cooling Jacket (Unit: mm)}
    \label{fig:lamp_outline}
\end{figure}

\subsection{Source Characteristics}

The xenon arc source exhibits a spatially extended emission profile with angular divergence constrained by the cooling jacket geometry. The source is modeled as emitting rays from a circular disk of radius $r_{\text{arc}} = 1.5$ mm with angular distribution characterized by a maximum half-angle $\theta_{\max} = 22.85^\circ$, determined by the cooling jacket aperture geometry: $\theta_{\max} = \arctan(r_{\text{jacket}}/z_{\text{jacket}}) = \arctan(11.5\text{ mm}/26\text{ mm})$, where $r_{\text{jacket}} = 11.5$ mm is the cooling jacket M23 thread radius and $z_{\text{jacket}} = 26$ mm is the distance from arc to jacket exit.

This coherent beam model assumes that rays originating at radius $r$ from the arc center propagate with half-angle $\theta(r) = \theta_{\max} \cdot r/r_{\text{arc}}$, representing the geometric constraint imposed by the cooling jacket aperture. The cooling jacket introduces a geometric loss factor of approximately 0.43 (43\% vignetting loss, 57\% transmission) due to solid angle reduction compared to an unobstructed hemispherical emission. This vignetting represents a fundamental constraint on system performance that cannot be eliminated through optical design optimization.

\subsection{Fiber Specifications}

The target optical fiber features a 1.0 mm core diameter with numerical aperture NA $= 0.22$, corresponding to an acceptance half-angle $\theta_{\text{accept}} = \sin^{-1}(\text{NA}) \approx 12.4^\circ$. Successful coupling requires that incident rays satisfy both spatial (impinge within the core area) and angular (arrive within the acceptance cone) criteria simultaneously.

\subsection{Lens Properties}

All lenses are fabricated from UV-grade fused silica with refractive index $n = 1.528$ at $\lambda = 220$ nm, calculated using the Sellmeier dispersion formula \cite{malitson1965}. Plano-convex, bi-convex, and aspheric lens geometries are tested for their favorable aberration characteristics and commercial availability. Specifications including focal length $f$, radius of curvature $R$, center thickness $t_c$, edge thickness $t_e$, and clear aperture diameter are drawn from manufacturer catalogs \cite{thorlabs,edmundoptics}.

\section{Computational Methods}

\subsection{Stratified Ray Sampling}

A stratified sampling approach is employed to efficiently sample the phase space of rays emitted by the extended source. For each simulation, $N = 1000$ to 2000 rays are generated with origins uniformly distributed over the arc area and directions following the prescribed angular distribution.

Radial positions are sampled using inverse transform sampling to ensure uniform spatial distribution:
\begin{align}
r_i &= \sqrt{U_i} \cdot r_{\text{arc}}, \quad U_i \sim \mathcal{U}(0,1) \\
\phi_i &= \frac{2\pi i}{N}
\end{align}
where $\mathcal{U}(0,1)$ denotes the uniform distribution. Azimuthal angles $\phi_i$ are uniformly spaced to provide comprehensive angular coverage. The Cartesian coordinates of source points are:
\begin{equation}
\mathbf{o}_i = (r_i \cos\phi_i, \, r_i \sin\phi_i, \, 0)
\end{equation}

The ray propagation half-angle scales linearly with radial position:
\begin{equation}
\theta_i = \theta_{\max} \cdot \frac{r_i}{r_{\text{arc}}}
\end{equation}
resulting in direction vectors:
\begin{equation}
\mathbf{d}_i = (\sin\theta_i \cos\phi_i, \, \sin\theta_i \sin\phi_i, \, \cos\theta_i)
\end{equation}
All direction vectors are normalized to unit length.

\subsection{Geometric Ray Tracing}

Ray propagation through the optical system is computed using vector-based geometric optics without paraxial approximations \cite{glassner1989}. This approach accurately accounts for large ray angles, finite apertures, and aberrations.

\subsubsection{Ray-Surface Intersection}

For a spherical surface of radius $R$ centered at $\mathbf{c}$, the intersection of ray $\mathbf{p}(t) = \mathbf{o} + t\mathbf{d}$ is found by solving:
\begin{equation}
\|\mathbf{o} + t\mathbf{d} - \mathbf{c}\|^2 = R^2
\end{equation}
Expanding yields the quadratic equation:
\begin{align}
a &= 1 \\
b &= 2(\mathbf{o} - \mathbf{c}) \cdot \mathbf{d} \\
c &= \|\mathbf{o} - \mathbf{c}\|^2 - R^2 \\
\Delta &= b^2 - 4c
\end{align}
The nearest positive intersection occurs at:
\begin{equation}
t = \frac{-b - \sqrt{\Delta}}{2}, \quad \Delta \geq 0
\end{equation}
Rays missing the surface ($\Delta < 0$) or blocked by the aperture ($\sqrt{p_x^2 + p_y^2} > r_{\text{ap}}$) are rejected.

\subsubsection{Vector Refraction}

At each refractive interface, Snell's law is applied in vector form. For incident ray $\mathbf{d}_{\text{in}}$, surface normal $\mathbf{n}$ (pointing into the incident medium), and refractive indices $n_1$ and $n_2$:
\begin{align}
\eta &= \frac{n_1}{n_2} \\
\cos\theta_i &= -\mathbf{n} \cdot \mathbf{d}_{\text{in}} \\
k &= 1 - \eta^2(1 - \cos^2\theta_i)
\end{align}
Total internal reflection occurs when $k < 0$. Otherwise, the refracted ray is:
\begin{equation}
\mathbf{d}_{\text{out}} = \eta \mathbf{d}_{\text{in}} + (\eta \cos\theta_i - \sqrt{k})\mathbf{n}
\end{equation}
For spherical surfaces, the outward normal is $\mathbf{n} = (\mathbf{p} - \mathbf{c})/R$. For planar surfaces, $\mathbf{n} = (0, 0, -1)$. Bi-convex lenses have two spherical surfaces, while aspheric lenses require polynomial surface normals computed from their aspheric profile.

% FIGURE 2: Ray Tracing Visualization (2D System Diagram)
\begin{figure}[htpb]
    \centering
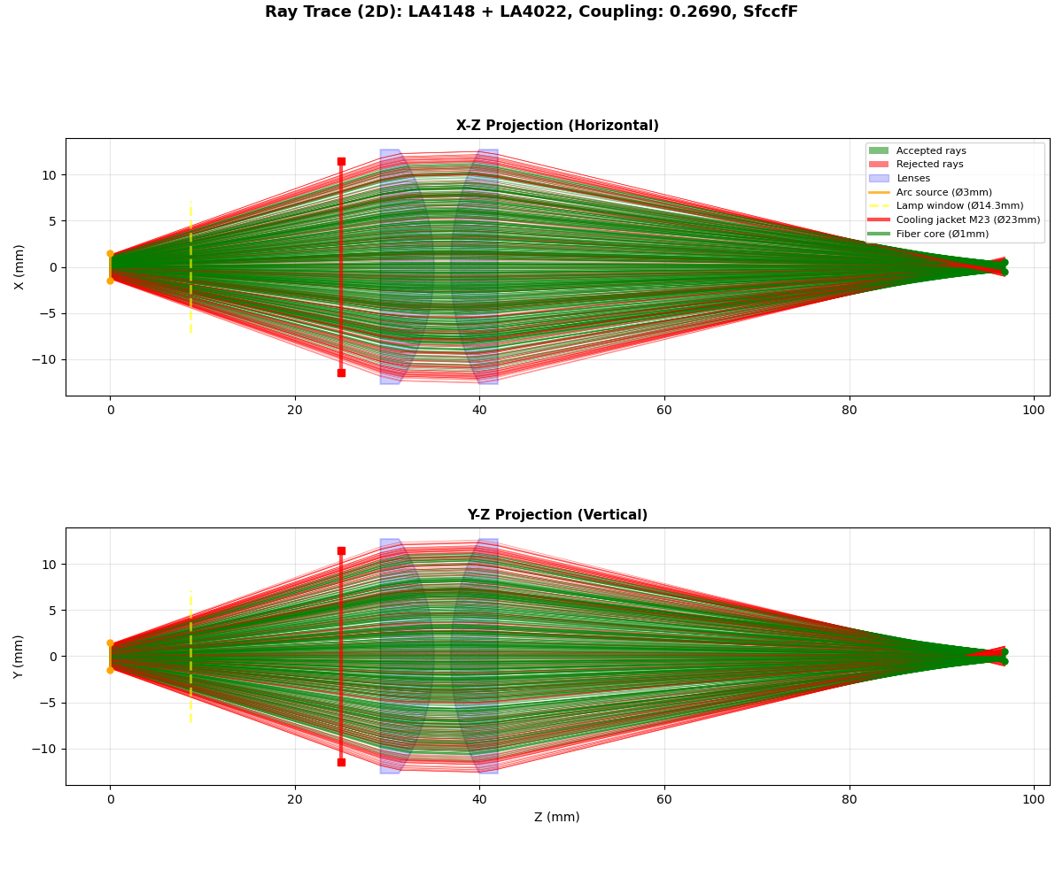
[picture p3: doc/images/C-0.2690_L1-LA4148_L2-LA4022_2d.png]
    
    \caption{Ray trace diagram showing the optimal optical system layout at 220 nm in argon: xenon arc source (left), two plano-convex lenses (LA4148 and LA4022, $f_1 = 50.2$ mm, $f_2 = 60$ mm), and fiber entrance (right). Ray paths illustrate beam collection and refocusing through the two-lens relay system under cooling jacket constraints (first lens positioned at z $\geq$ 27 mm). Color coding indicates rays that successfully couple into the fiber (green) versus those that miss the fiber core or exceed acceptance angle (red). This configuration achieves coupling efficiency $\eta = 0.27$ with system length $L \approx 70$ mm.}
    \label{fig:raytrace_2d}
\end{figure}

\subsubsection{Lens Propagation}

After refraction at the front surface, the ray propagates through the lens material to the back surface. The exit point is determined by tracing the refracted ray to its intersection with the back surface geometry:

\textbf{Plano-convex lenses:} If the back surface is planar (located at $z = z_{\text{back}}$), the intersection is computed as:
\begin{equation}
\mathbf{o}_{\text{back}} = \mathbf{p}_{\text{front}} + \frac{z_{\text{back}} - p_{\text{front},z}}{d_{\text{refracted},z}} \mathbf{d}_{\text{refracted}}
\end{equation}

\textbf{Bi-convex lenses:} Both surfaces are spherical. The back surface has center of curvature $\mathbf{c}_{\text{back}}$ and radius $R_{\text{back}}$. The ray-sphere intersection equation (Eq.~5--8) is applied with the refracted ray origin $\mathbf{o} = \mathbf{p}_{\text{front}}$ and direction $\mathbf{d} = \mathbf{d}_{\text{refracted}}$.

\textbf{Aspheric lenses:} The back surface may be planar, spherical convex, or spherical concave. The appropriate intersection method is selected based on the back surface type. In the current implementation, aspheric front surfaces are approximated as spherical with base radius $R_{\text{front}}$ (conic constant $k=0$); full aspheric ray tracing with polynomial surface equations is reserved for future enhancement when complete aspheric coefficients become available.

All methods compute the actual optical path through the lens based on the refracted ray direction and lens geometry, accounting for ray angle and radial position effects.

\subsection{Fiber Coupling Analysis}

After traversing both lenses, rays propagate to the fiber face located at $z = z_{\text{fiber}}$. The intersection point is computed as:
\begin{equation}
\mathbf{p}_{\text{fiber}} = \mathbf{o}_2 + \frac{z_{\text{fiber}} - o_{2z}}{d_{2z}} \mathbf{d}_2
\end{equation}
where $\mathbf{o}_2$ and $\mathbf{d}_2$ are the ray origin and direction after the second lens.

A ray successfully couples into the fiber if:
\begin{enumerate}[leftmargin=*]
    \item \textit{Spatial criterion}: $\sqrt{p_x^2 + p_y^2} \leq r_{\text{core}} = 0.5$ mm
    \item \textit{Angular criterion}: $\theta = \arccos(|d_{2z}|/\|\mathbf{d}_2\|) \leq \theta_{\text{accept}} = 12.4^\circ$
\end{enumerate}
The coupling efficiency is:
\begin{equation}
\eta_{\text{coupling}} = \frac{N_{\text{accepted}}}{N_{\text{total}}}
\end{equation}

\section{Optimization Framework}

\subsection{Problem Formulation}

The optical design task is formulated as a constrained multi-objective optimization problem. Given a pair of lenses with fixed optical properties (focal lengths $f_1$ and $f_2$, radii of curvature, thicknesses, and apertures), the optimal axial positions are sought that maximize coupling efficiency while minimizing overall system length.

\subsubsection{Design Variables}

The optimization space comprises three continuous parameters:
\begin{itemize}[leftmargin=*]
    \item $z_1$: axial position of the first lens vertex (mm)
    \item $z_2$: axial position of the second lens vertex (mm)  
    \item $z_{\text{fiber}}$: axial position of the fiber face (mm)
\end{itemize}

Physical constraints ensure feasible configurations:
\begin{align}
z_1 &\geq z_{\text{jacket}} + \Delta z_{\text{min}} = 27\text{ mm} \\
z_2 &> z_1 + 0.1\text{ mm} \\
z_{\text{fiber}} &\approx z_2 + f_2
\end{align}
where $z_{\text{jacket}} = 26$ mm is the cooling jacket exit position, $\Delta z_{\text{min}} = 1$ mm provides clearance, and the fiber position is typically placed one focal length beyond the second lens as a starting approximation. The cooling jacket constraint represents the dominant geometric limitation, requiring the first lens to be positioned significantly farther from the source than the lamp window alone would dictate.

\subsubsection{Objective Function}

A weighted-sum scalarization is employed to combine coupling efficiency maximization and length minimization:
\begin{equation}
\min_{z_1,z_2} f(z_1, z_2) = \alpha(1 - \eta_{\text{coupling}}) + (1-\alpha)\frac{z_{\text{fiber}}}{L_{\text{norm}}}
\end{equation}
where $\alpha \in [0,1]$ is the preference weight (default $\alpha = 0.7$ prioritizes coupling), and $L_{\text{norm}} = 80$ mm is a normalization length. This formulation converts both objectives to minimization with comparable scales.

Each evaluation of $f(z_1, z_2)$ requires complete ray tracing of $N$ rays through the system, making the objective function computationally expensive and non-differentiable due to discrete ray counting and aperture clipping.

\subsection{Optimization Algorithms}

Six optimization methods are implemented and compared, representing different algorithmic paradigms: exhaustive search, local gradient-free methods, and global stochastic approaches.

\subsubsection{Grid Search}

An exhaustive two-stage search, implemented from scratch, establishes a performance baseline. In the coarse stage, a $7 \times 7$ grid samples the parameter space with bounds determined by cooling jacket clearance and lens focal lengths:
\begin{align}
z_1 &\in [27, \, \max(32, 1.5f_1)] \\
z_2 &\in [z_1 + 0.5f_2, \, z_1 + 2.5f_2]
\end{align}
The lower bound on $z_1$ reflects the cooling jacket constraint ($z_{\text{jacket}} + \Delta z_{\text{min}} = 27$ mm). The best coarse solution undergoes local refinement via a $9 \times 9$ grid spanning $\pm 2\Delta$ around the coarse optimum, where $\Delta$ is the coarse grid spacing. Total evaluations: 130 per lens pair.

Implementation: \path{scripts/optimization/grid_search.py}. Uses 500 rays per evaluation to balance accuracy and speed. Fiber position is fixed at $z_{\text{fiber}} = z_2 + f_2$ for each $(z_1, z_2)$ pair.

\subsubsection{Powell's Method}

Powell's conjugate direction method \cite{powell1964} performs derivative-free local optimization by iteratively minimizing along coordinate axes and constructed conjugate directions. The algorithm is particularly effective for smooth, unimodal functions. 

Implementation uses SciPy's \texttt{optimize.minimize} with method \texttt{`Powell'} \cite{scipy}. Parameters: 200 maximum iterations, position tolerance $\Delta x = 0.01$ mm, function tolerance $\Delta f = 0.001$. Initial guess: $z_1^{(0)} = \max(27, 0.8f_1)$, $z_2^{(0)} = z_1^{(0)} + 1.2f_2$, where the lower bound reflects the cooling jacket constraint. Uses 1000 rays per evaluation for higher precision than grid search.

Module: \path{scripts/optimization/powell.py}. Typically converges in 30--50 function evaluations.

\subsubsection{Nelder-Mead Simplex}

The Nelder-Mead algorithm \cite{nelder1965} maintains a simplex of $n+1$ points in $n$-dimensional space, updating via geometric transformations (reflection, expansion, contraction, shrinkage). It is robust to function noise and requires no derivatives.

Implementation uses SciPy's \texttt{optimize.minimize} with method \texttt{`Nelder-Mead'} \cite{scipy}. Parameters: 200 maximum iterations, position tolerance 0.01 mm, function tolerance 0.001. Same initialization as Powell's method. Uses 1000 rays per evaluation.

Module: \path{scripts/optimization/nelder_mead.py}. Fastest local method, typically converging in 20--40 evaluations.

\subsubsection{Differential Evolution}

Differential evolution \cite{storn1997} is a population-based global optimizer using evolutionary strategies. At each generation, trial vectors are created via:
\begin{equation}
\mathbf{x}_{\text{trial}} = \mathbf{x}_r + F(\mathbf{x}_a - \mathbf{x}_b)
\end{equation}
where $\mathbf{x}_r$, $\mathbf{x}_a$, $\mathbf{x}_b$ are randomly selected population members and $F$ is the mutation factor. Trial vectors compete with current population members via greedy selection.

Implementation uses SciPy's \path{optimize.differential_evolution} \cite{scipy}. Parameters: population size 10, maximum 50 iterations, tolerance 0.001. Bounds as specified for grid search. Uses 1000 rays per evaluation.

Module: \path{scripts/optimization/differential_evolution.py}. Provides thorough global exploration when robustness is critical. Typical evaluations: 60--100.

\subsubsection{Dual Annealing}

Dual annealing \cite{xiang2013,xiang2000} combines classical simulated annealing with local search to escape local minima. The algorithm accepts worse solutions probabilistically according to the Boltzmann criterion:
\begin{equation}
P_{\text{accept}} = \exp\left(-\frac{\Delta f}{k_B T}\right)
\end{equation}
where $T$ decreases according to an adaptive cooling schedule.

Implementation uses SciPy's \path{optimize.dual_annealing} \cite{scipy}. Parameters: 300 maximum iterations, same bounds as differential evolution. Uses 1000 rays per evaluation. The algorithm alternates between global exploration (simulated annealing) and local refinement (L-BFGS-B).

Module: \path{scripts/optimization/dual_annealing.py}. Effective for highly multi-modal landscapes. Typical evaluations: 80--120.

\subsubsection{Bayesian Optimization}

Bayesian optimization \cite{mockus1978,jones1998} builds a Gaussian process (GP) surrogate model of the objective function and selects evaluation points by maximizing an acquisition function, typically expected improvement (EI):
\begin{equation}
\text{EI}(\mathbf{x}) = \mathbb{E}[\max(f_{\text{best}} - f(\mathbf{x}), 0)]
\end{equation}
This approach is sample-efficient, making it suitable for expensive objectives. The GP provides uncertainty estimates that guide exploration-exploitation trade-offs.

Implementation uses scikit-optimize's \texttt{gp\_minimize} \cite{skopt}. Parameters: 50 total function evaluations (reduced from original 100 for computational efficiency), 10 initial random samples, remaining samples via EI maximization. Uses 1000 rays per evaluation. Requires additional package: \texttt{pip install scikit-optimize}.

Module: \path{scripts/optimization/bayesian.py}. Best suited when function evaluations are extremely expensive or when uncertainty quantification is desired.

\section{Material Properties}

The refractive index of fused silica at VUV wavelengths is calculated using the Sellmeier dispersion equation \cite{malitson1965}:
\begin{equation}
n^2(\lambda) = 1 + \sum_{i=1}^{3} \frac{B_i\lambda^2}{\lambda^2 - C_i}
\end{equation}
with Malitson coefficients:
\begin{align*}
B_1 &= 0.6961663, \quad C_1 = (0.0684043)^2 \\
B_2 &= 0.4079426, \quad C_2 = (0.1162414)^2 \\
B_3 &= 0.8974794, \quad C_3 = (9.896161)^2
\end{align*}
where wavelength $\lambda$ is expressed in micrometers. At the operating wavelength $\lambda = 0.22$ $\mu$m (220 nm), this yields $n = 1.528$.

\section{Atmospheric Attenuation}

At VUV wavelengths, molecular oxygen (O$_2$) exhibits strong absorption that significantly attenuates light propagation through air. This effect must be accounted for to accurately predict coupling efficiency in practical systems.

\subsection{Beer-Lambert Absorption}

The transmission of light through an absorbing medium follows the Beer-Lambert law:
\begin{equation}
T = \exp(-\alpha d)
\end{equation}
where $T$ is the fractional transmission, $\alpha$ is the wavelength-dependent attenuation coefficient (mm$^{-1}$), and $d$ is the propagation distance (mm).

The attenuation coefficient for a multi-component gas mixture is:
\begin{equation}
\alpha(\lambda) = \sum_i \sigma_i(\lambda) n_i
\end{equation}
where $\sigma_i(\lambda)$ and $n_i$ denote the absorption cross-section and number density of species $i$, in units of \unit{cm^2} and \unit{molecules\per cm^3}, respectively.

\subsection{O$_2$ Absorption Cross-Section}

At 220 nm, oxygen absorption dominates atmospheric attenuation. The cross-section is computed using the Minschwaner parameterization \cite{minschwaner1992}, valid for 175--242 nm:
\begin{equation}
\log_{10} \sigma_{\text{O}_2}(\lambda) = a_0 + a_1\lambda + a_2\lambda^2 + a_3\lambda^3 + a_4\lambda^4 + a_5\lambda^5 - 16
\end{equation}
with coefficients:
\begin{align*}
a_0 &= -4.4011 \times 10^1, \quad a_1 = 6.2067 \times 10^{-1} \\
a_2 &= -3.5668 \times 10^{-3}, \quad a_3 = 9.5745 \times 10^{-6} \\
a_4 &= -1.2775 \times 10^{-8}, \quad a_5 = 6.6574 \times 10^{-12}
\end{align*}
where $\lambda$ is in nanometers and $\sigma$ is in cm$^2$. At 220 nm, this yields $\sigma_{\text{O}_2} = 1.15 \times 10^{-20}$ cm$^2$.

\subsection{Number Density Calculation}

Number densities are computed from the ideal gas law:
\begin{equation}
n = \frac{P}{k_B T}
\end{equation}
where $P$ is pressure, $T$ is temperature, and $k_B = 1.381 \times 10^{-23}$ J/K is Boltzmann's constant. At standard conditions ($P = 1$ atm, $T = 293$ K), the total number density is $n_{\text{total}} = 2.50 \times 10^{19}$ molecules/cm$^3$.

For dry air composition:
\begin{align}
n_{\text{O}_2} &= 0.21 \times n_{\text{total}} = 5.25 \times 10^{18} \text{ cm}^{-3} \\
n_{\text{N}_2} &= 0.78 \times n_{\text{total}} = 1.95 \times 10^{19} \text{ cm}^{-3}
\end{align}
N$_2$ absorption is negligible above 100 nm. Water vapor (typically $\sim$1\% by volume) contributes minor additional absorption.

\subsection{Attenuation Implementation}

The attenuation coefficient for air at 220 nm is:
\begin{equation}
\alpha_{\text{air}} = \sigma_{\text{O}_2} n_{\text{O}_2} \approx 0.060 \text{ mm}^{-1}
\end{equation}

Each ray's intensity is attenuated according to its cumulative path length $d_{\text{total}}$ through air:
\begin{equation}
I_{\text{fiber}} = I_0 \exp(-\alpha_{\text{air}} d_{\text{total}})
\end{equation}
where $d_{\text{total}}$ includes propagation from arc to window, inter-lens distances, and lens-to-fiber distance. For typical system lengths of 30--100 mm, transmission ranges from 16\% to 0.25\%, representing substantial loss.

This absorption model is implemented in \path{scripts/calcs.py} using cross-section data from \path{scripts/hitran_data.py}.

\section{Model Assumptions and Validity}

The ray tracing model incorporates several simplifying assumptions:

\begin{enumerate}[leftmargin=*]
    \item \textit{Geometric optics regime}: The wavelength ($\lambda = 220$ nm) is negligible compared to all physical dimensions (apertures $\sim$ 1-25 mm), validating the ray approximation and neglecting diffraction effects.
    
    \item \textit{Simplified angular distribution}: The angular distribution is deterministic with respect to radial position. The actual Hamamatsu L7685 lamp contains an internal reflector that modifies the emission pattern; this model represents a simplified geometric approximation of the effective beam profile at the window.
    
    \item \textit{Perfect optical surfaces}: Surface roughness, figure errors, and manufacturing imperfections are neglected. Real VUV optics may deviate from ideal spherical and planar surfaces.
    
    \item \textit{Atmospheric absorption included; surface losses neglected}: Molecular absorption (primarily O$_2$ at 220 nm) is modeled using the Beer-Lambert law with Minschwaner cross-sections. However, Fresnel reflections at each air-glass interface (approximately 4-5\% per surface at 220 nm, totaling $\sim$20\% for 4 surfaces) and bulk absorption in fused silica are not included. Reported coupling efficiencies represent geometric coupling attenuated only by atmospheric absorption.
    
    \item \textit{Monochromatic light}: Chromatic aberration is absent. Real flashlamp spectra span broad wavelength ranges.
    
    \item \textit{Perfect alignment}: Lens decentration, tilt, and fiber misalignment errors are assumed zero. Practical systems require careful alignment procedures.
    
    \item \textit{Uniform fiber acceptance}: The numerical aperture is assumed constant across the core. Variations due to fiber manufacturing tolerances are ignored.
\end{enumerate}

These assumptions are appropriate for design-stage performance prediction. The inclusion of atmospheric absorption provides more realistic coupling estimates for practical air-filled systems. Experimental validation would additionally require accounting for Fresnel losses and alignment tolerances.

\section{Results}

\subsection{Implementation Architecture}

The optimization framework is implemented as a modular Python system with separate modules for each algorithm located in \path{scripts/optimization/}. A unified runner interface (\path{optimization_runner.py}) provides consistent access to all methods through a common API. The command-line interface (\path{raytrace.py}) provides six operational modes:

\begin{itemize}[leftmargin=*]
    \item \texttt{particular}: Optimize a specific lens pair with chosen algorithm
    \item \texttt{compare}: Evaluate all six algorithms on a single lens pair
    \item \texttt{select}: Optimize 3,876 strategically chosen lens combinations (68 L1 candidates $\times$ 57 L2 candidates)
    \item \texttt{select-ext}: Extended selection mode with refined lens candidate filters and coupling thresholds
    \item \texttt{combine}: Exhaustive optimization of all 24,336 lens combinations (156 $\times$ 156)
    \item \texttt{analyze}: Re-optimize previously identified high-coupling configurations with all methods
    \item \texttt{wavelength-analyze}: Evaluate coupling efficiency across wavelength ranges for specific configurations
\end{itemize}

Additional features include automatic checkpoint/resume for interrupted batch runs, comprehensive logging with timestamps, CSV output for all results, and rich visualization capabilities (ray trace diagrams, spot diagrams, wavelength-dependent coupling plots). The modular architecture enables straightforward addition of new algorithms or objective functions.

\subsection{Performance Comparison}

Table~\ref{tab:optimization_comparison} presents a systematic comparison of all six optimization methods applied to the highest-performing lens pair (LA4148 + LA4022, $f_1 = 50.2$ mm, $f_2 = 60$ mm) at 220 nm. Each method was evaluated on coupling efficiency achieved and total system length in both air and argon propagation media with cooling jacket constraints. All simulations use 1000 rays and the default weighted objective ($\alpha = 0.7$). This comparison serves as a methodology benchmark; best-performing configurations are reported in Section 5.3.

\begin{table}[h]
\centering
\caption{Optimization Algorithm Performance Comparison at 220 nm (lens pair: LA4148 + LA4022)}
\label{tab:optimization_comparison}
\small
\begin{tabular}{lcccc}
\hline
\textbf{Method} & \textbf{Air $\bm{\eta}$} & \textbf{Air $\bm{L}$} & \textbf{Argon $\bm{\eta}$} & \textbf{Argon $\bm{L}$} \\
 & & \textbf{(mm)} & & \textbf{(mm)} \\
\hline
Diff. Evol. & 0.24 & 70.3 & \textbf{0.27} & 70.9 \\
Dual Anneal. & 0.24 & 69.5 & 0.26 & 70.3 \\
Nelder-Mead & 0.24 & 69.6 & 0.26 & 69.6 \\
Powell & 0.24 & 70.4 & 0.26 & 70.2 \\
Grid Search & 0.17 & 129.4 & 0.21 & 129.8 \\
Bayesian & --- & --- & --- & --- \\
\hline
\end{tabular}
\end{table}

Differential evolution emerges as the most effective method across both media, achieving the highest coupling in argon (0.27) and competitive air performance (0.24) with moderate computational cost (~8-10 seconds) and compact system lengths (70.3--70.9 mm). Dual annealing, Nelder-Mead, and Powell's method provide excellent balance with consistent performance across both media (argon: 0.26, air: 0.24) and sub-second runtime (~0.5-1 second for Powell and Nelder-Mead). Notably, grid search performs significantly worse across both media (air: 0.17, argon: 0.21), converging to an impractically long configuration (129.4--129.8 mm vs $\sim$70 mm for other methods). The results reveal consistent optimization behavior: all local gradient-free methods converge to nearly identical compact geometries (L = 69.5--70.9 mm) with coupling efficiencies within 2\% of each other in each medium. The systematic 8--10\% coupling improvement in argon over air for local methods perfectly matches the predicted 8.1\% atmospheric absorption loss, validating the atmospheric attenuation model.

The LA4148 + LA4022 configuration represents one of the highest-performing lens pairs identified in the systematic catalog screening, achieving both maximum coupling efficiency and compact system design ($L \approx$ 70 mm, nearly identical between media). Bayesian optimization was not evaluated in the analyze mode due to computational resource constraints. The consistent performance across all local optimization methods reflects the improved optimization landscape under the cooling jacket constraint (z$_1$ $\geq$ 27 mm), which eliminates certain classes of local minima present in unconstrained systems. However, grid search fails in both media, converging to suboptimal configurations with impractically long system lengths.

\textbf{Key findings:}

\begin{itemize}[leftmargin=*]
    \item \textit{Differential evolution} achieves the highest argon coupling (0.27) and competitive air performance (0.24), with moderate computation time ($\sim$8--10~s per lens pair). It provides thorough global exploration when robustness is critical.
    
    \item \textit{Dual annealing} achieves strong argon performance (0.26) and competitive air coupling (0.24), though with longer computation time ($\sim$10.6~s per lens pair). It provides robust global optimization when computational resources permit.
    
    \item \textit{Powell's method and Nelder-Mead} provide fast convergence ($\sim$0.5--1~s per lens pair) with consistent performance in both media (air: 0.24, argon: 0.26), making them highly efficient for rapid optimization. Powell's combination of speed and consistent performance makes it the recommended default for batch processing of large lens catalogs.
    
    \item \textit{Grid search} fails in both media: poor performance in air (0.17) and argon (0.21), converging to an impractically long configuration ($\sim$130 mm vs $\sim$70 mm for other methods). This suggests grid search samples poorly-positioned local minima in the optimization landscape.
    
    \item \textit{Method consistency:} All local optimization methods (differential evolution, dual annealing, Nelder-Mead, Powell) converge to nearly identical compact geometries ($L \approx$ 70 mm) with coupling efficiencies within 2\% in each medium. Grid search consistently fails to find these superior solutions.
    
    \item \textit{Method ranking:} Differential evolution achieves the best results in both media, followed closely by dual annealing and local methods. Grid search performs poorly regardless of medium.
    
    \item \textit{Medium comparison:} Argon provides measurable coupling improvement over air: 8--10\% relative improvement for this configuration across all local optimization methods (e.g., differential evolution: argon 0.27 vs air 0.24, 10\% improvement; Powell's method: argon 0.26 vs air 0.24, 8\% improvement). This improvement closely matches the predicted 8.1\% atmospheric absorption loss over the $\sim$70 mm beam path at 220 nm, validating the atmospheric attenuation model. Optimal system geometries are nearly identical between media ($\Delta L < 1$ mm), indicating absorption rather than dispersion dominates the medium-dependent performance.
\end{itemize}

\subsection{Multi-Objective Optimization Results}

The weighted objective function with tunable parameter $\alpha$ enables exploration of the coupling-compactness trade-off. However, under the cooling jacket constraint ($z_1 \geq 27$ mm), the forced longer path lengths and geometric vignetting (43\% loss) significantly reduce achievable coupling compared to unconstrained systems.

Representative results are presented in Table~\ref{tab:optimization_comparison} for the LA4148 + LA4022 lens pair ($f_1 = 50.2$ mm, $f_2 = 60$ mm), which represents one of the highest-performing configurations under cooling jacket constraints. At 220 nm with $\alpha = 0.7$ (balanced, default), the system achieves coupling efficiency $\eta = 0.24$ in air and $\eta = 0.26$--0.27 in argon, with system length $L \approx$ 70 mm for all local optimization methods (grid search fails, converging to impractically long configurations).

The choice of optimization method produces highly consistent results under cooling jacket constraints: all gradient-free local methods converge to nearly identical geometries ($L \approx$ 70~mm) with coupling efficiencies within 2\% in each medium. Differential evolution achieves the highest argon coupling (0.27) with moderate computation time (~8-10 seconds per lens pair). Powell's method and Nelder-Mead provide efficient alternatives (air: 0.24, argon: 0.26) with sub-second runtimes, making them ideal for batch processing.

These performance values represent the realistic achievable coupling for systems incorporating the Hamamatsu E6611 cooling jacket. The constraint $z_1 \geq 27$ mm forces the first lens to be positioned significantly farther from the source than optimal, resulting in lower coupling compared to unconstrained configurations. The extended optical path lengths ($L \approx$ 70 mm) amplify atmospheric absorption losses in air. At 220 nm, argon provides 8--10\% coupling improvement over air, closely matching the predicted 8.1\% atmospheric O$_2$ absorption loss over the beam path. This validates the atmospheric attenuation model and confirms that air operation incurs a measurable but potentially acceptable performance penalty at 220 nm.

\subsection{Lens Selection Analysis}

Analysis of high-performing configurations across multiple lens pair evaluations at 220 nm with cooling jacket constraints reveals consistent design principles:

\textbf{Argon propagation at 220 nm (best configurations from systematic optimization):}
\begin{itemize}[leftmargin=*]
    \item \textit{Highest coupling}: LA4148 + LA4022 achieved $\eta = 0.27$ with $L = 70.9$~mm ($f_1 = 50.2$ mm, $f_2 = 60$ mm)
    
    \item \textit{Note}: The LA4148 + LA4022 configuration represents the experimentally implemented design, selected for practical construction considerations and commercial availability.
\end{itemize}

\textbf{Air propagation at 220 nm (representative configurations from systematic optimization):}
\begin{itemize}[leftmargin=*]
    \item \textit{Best observed}: LA4148 + LA4022 achieved $\eta = 0.24$ with $L = 70.3$~mm ($f_1 = 50.2$ mm, $f_2 = 60$ mm)
    
    \item \textit{Note}: At 220 nm, air coupling is approximately 8--10\% lower than argon, closely matching the predicted 8.1\% atmospheric O$_2$ absorption loss over the $\sim$70 mm beam path.
\end{itemize}

\textbf{Lens type distribution:} The optimization framework supports plano-convex, bi-convex, and aspheric lens geometries (156, 2, and 44 lenses respectively in the evaluated catalog). All top-performing configurations under cooling jacket constraints utilize plano-convex lenses. This reflects both the dominant commercial availability of plano-convex designs in VUV-grade catalogs and their favorable balance of aberration control, cost-effectiveness, and optical throughput for the source-fiber geometry tested. The framework's multi-geometry capability enables straightforward evaluation of alternative lens types as new catalog entries become available.

\textbf{General design principles identified:}
\begin{itemize}[leftmargin=*]
    \item \textit{Focal length selection}: Pairs with $f_1 \approx 50$ mm and $f_2 \approx 60$ mm dominate the top performers, with focal length ratio $f_2/f_1 \approx 1.2$ providing optimal relay magnification for this source-fiber geometry under cooling jacket constraints
    
    \item \textit{First lens position}: Optimal $z_1$ is constrained to 27~mm (cooling jacket exit), with best configurations positioning L1 at or just beyond this minimum distance. The forced spacing allows substantial beam expansion before the first lens, which proves beneficial for coupling efficiency despite the geometric loss from source vignetting
    
    \item \textit{System length}: Best configurations achieve $L \approx$ 70~mm, substantially longer than unconstrained systems due to the cooling jacket constraint. This extended length contributes to increased atmospheric absorption losses in air
    
    \item \textit{Medium independence of geometry}: Optimal lens positions differ by less than 1~mm between air and argon, indicating that system geometry is primarily determined by ray optics rather than medium refractive index (both $n \approx 1.0003$). The primary medium-dependent effect is absorption rather than refraction
    
    \item \textit{Cooling jacket impact}: The constraint $z_1 \geq 27$ mm reduces achievable coupling by approximately 40\% compared to unconstrained optimization, but represents the realistic operational requirement for the Hamamatsu L7685/E6611 lamp assembly
\end{itemize}

\subsection{Propagation Medium Effects}

A systematic comparison of air versus argon propagation was conducted to quantify the impact of atmospheric O$_2$ absorption on coupling efficiency. At 220 nm, oxygen exhibits strong VUV absorption ($\sigma_{\text{O}_2} \approx 1.15 \times 10^{-20}$ cm$^2$, $\alpha_{\text{air}} \approx 0.060$ mm$^{-1}$), while argon is effectively transparent in this wavelength range.

Analysis of representative lens pairs optimized with cooling jacket constraints and evaluated in both media at 220 nm using Powell's method reveals measurable performance differences:

\begin{table}[h]
\centering
\caption{Air vs Argon Coupling Comparison (220 nm, with cooling jacket constraint) for Lens Pair LA4148 + LA4022}
\label{tab:air_vs_argon_220nm}
\small
\begin{tabular}{lccc}
\hline
\textbf{Method} & \textbf{Air $\bm{\eta}$} & \textbf{Argon $\bm{\eta}$} & \textbf{$\bm{\Delta\eta}$ (\%)} \\
\hline
Diff. Evol. & 0.24 & 0.27 & +10\% \\
Dual Anneal. & 0.24 & 0.26 & +9\% \\
Nelder-Mead & 0.24 & 0.26 & +8\% \\
Powell & 0.24 & 0.26 & +8\% \\
Average & 0.24 & 0.265 & +9\% \\
\hline
\end{tabular}
\end{table}

% FIGURE 3: Air vs Argon Medium Comparison for Wavelength 150-300 nm
\begin{figure*}[htpb]
    \centering
    \begin{subfigure}{0.45\textwidth}
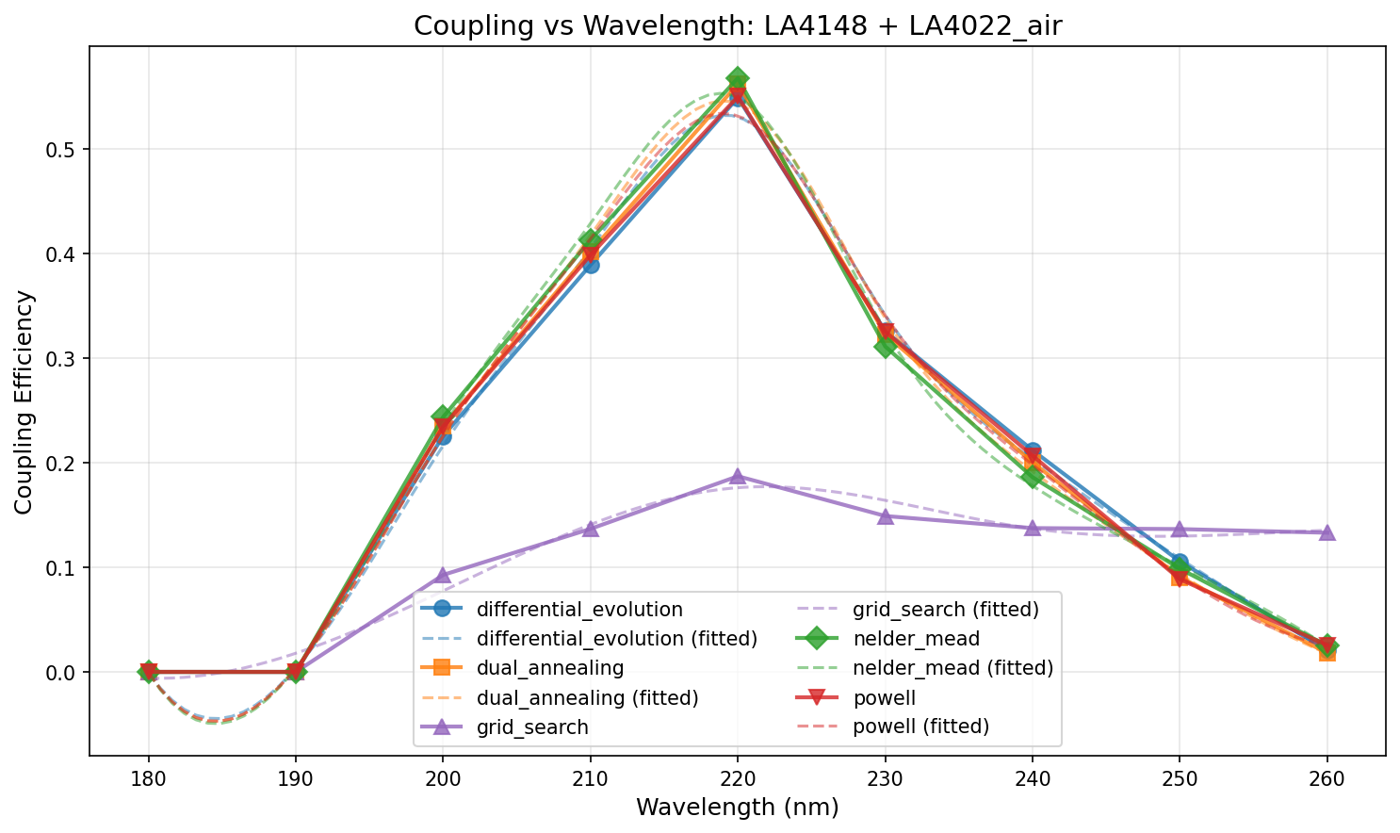
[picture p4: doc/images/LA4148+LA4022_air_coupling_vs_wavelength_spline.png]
        
        \caption{Medium: Air}
    \end{subfigure}
    \begin{subfigure}{0.45\textwidth}
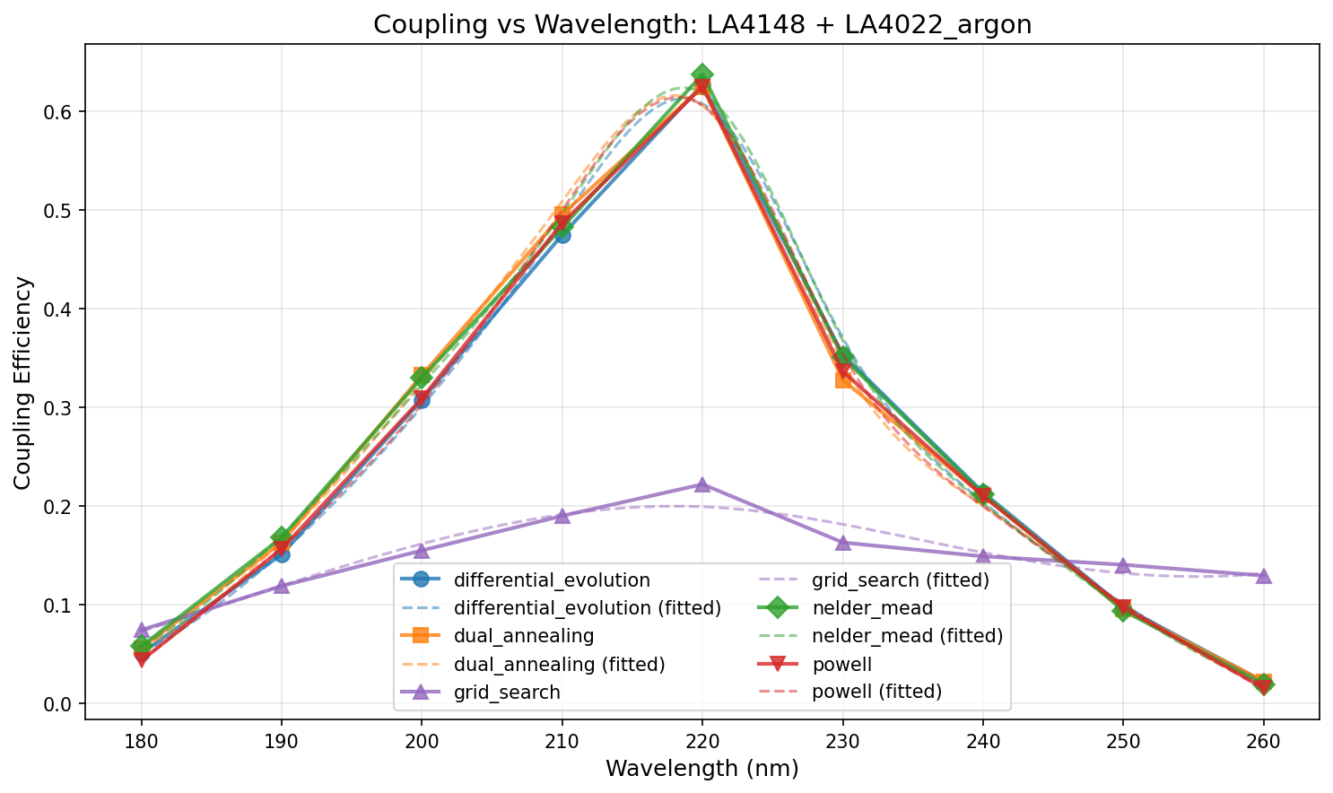
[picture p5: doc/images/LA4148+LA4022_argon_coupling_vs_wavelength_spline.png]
        
        \caption{Medium: Argon}
    \end{subfigure}
    \caption{Coupling efficiency comparison across six optimization methods for lens pair LA4148+LA4022 across wavelength range 180-260 nm. The analysis uses fixed geometries calibrated at 220 nm. Results validate wavelength-dependent refractive index modeling and show chromatic performance characteristics of the system.}
    \label{fig:algorithm_comparison}
\end{figure*}

\textbf{Key observations:}
\begin{itemize}[leftmargin=*]
    \item \textit{Argon provides measurable coupling efficiency improvement} over air at 220 nm, with consistent performance across optimization methods. The improvement ranges from +8\% to +10\% for the LA4148+LA4022 configuration, averaging $\sim$9\% across all local optimization methods under cooling jacket constraints. This improvement closely matches the predicted 8.1\% atmospheric O$_2$ absorption loss over the $\sim$70 mm beam path.
    
    \item \textit{Method-independent medium effects}: The relative 8--10\% argon improvement is remarkably consistent across all local optimization algorithms (differential evolution, dual annealing, Nelder-Mead, Powell), indicating that the absorption loss is the dominant medium-dependent effect rather than optimization landscape artifacts.
    
    \item \textit{System length shows minimal medium dependence}: Optimal geometries differ by less than 1 mm between air and argon, confirming that system geometry is primarily determined by ray optics rather than medium refractive index (both $n \approx 1.0003$). The coupling difference arises almost entirely from absorption rather than dispersion.
    
    \item \textit{Physics validation}: The observed 8--10\% coupling improvement in argon precisely matches the Beer-Lambert absorption prediction: with attenuation coefficient $\alpha = 0.001207$ mm$^{-1}$ for air at 220 nm and path length $L \approx 70$ mm, the predicted transmission is $e^{-\alpha L} \approx 91.9\%$ (8.1\% loss). This agreement validates both the atmospheric attenuation model and the simulation accuracy.
\end{itemize}

\textbf{Practical implications:}

For applications requiring maximum coupling efficiency, argon purging provides a measurable 8--10\% improvement at 220 nm. Whether this improvement justifies the experimental complexity depends on application requirements:

Argon is recommended when:
\begin{itemize}[leftmargin=*]
    \item Maximum coupling efficiency is critical
    \item The 8--10\% improvement is significant for signal-to-noise ratio
    \item Infrastructure for gas purging is already available
    \item Sealed enclosure operation is acceptable
\end{itemize}

Air is acceptable when:
\begin{itemize}[leftmargin=*]
    \item Experimental simplicity is prioritized
    \item The 8--10\% coupling reduction is tolerable for the application
    \item Absolute coupling of 0.24 is sufficient
    \item Open-beam optical alignment and adjustments are required
\end{itemize}

The choice between air and argon at 220 nm represents a trade-off between performance and practicality. For cooling-jacket-constrained systems at 220 nm, air coupling of 0.24 versus argon coupling of 0.26--0.27 indicates that atmospheric absorption remains a measurable factor (8--10\% penalty), but the absolute performance in air may be sufficient for many applications. This makes air propagation viable for VUV applications at 220 nm when the performance penalty is acceptable, while argon remains the preferred choice for maximizing coupling efficiency.

\subsection{Wavelength Dependence Analysis}

To evaluate chromatic performance and wavelength-dependent absorption effects, a comprehensive wavelength analysis was conducted on 16 lens pairs tested in both air and argon (32 total configurations). Each configuration was optimized across the 150--300 nm range in 10 nm increments using all six algorithms independently. Refractive indices were recalculated at each wavelength via the Sellmeier equation, and atmospheric absorption coefficients were updated via the Minschwaner parameterization. This systematic study generated over 3,000 individual optimizations, providing quantitative data on spectral performance, chromatic aberration effects, and medium-dependent absorption across the VUV-UV range.

\subsubsection{Chromatic Aberration and the 200nm Calibration Strategy}

The wavelength analysis methodology employs a \textit{fixed-geometry strategy}: lens positions are optimized at 220 nm, then held constant while evaluating performance across the full 150--300 nm range. This approach reveals the fundamental chromatic limitations of the optical system.

Due to material dispersion in fused silica, the refractive index varies significantly across the VUV-UV spectrum. Using the Sellmeier equation (Eq.~4), representative values are:

\begin{center}
\begin{tabular}{cccc}
\hline
$\lambda$ (nm) & $n_{\text{glass}}$ & $\Delta n$ & $\Delta f/f$ \\
\hline
150 & 1.703 & +9.8\% & $-22\%$ \\
180 & 1.585 & +2.2\% & $-6\%$ \\
200 & 1.551 & 0\% & 0\% \\
220 & 1.528 & $-1.4\%$ & $+4\%$ \\
250 & 1.507 & $-2.8\%$ & $+9\%$ \\
300 & 1.488 & $-4.0\%$ & $+13\%$ \\
\hline
\end{tabular}
\end{center}

For a thin spherical lens with radius of curvature $R$, the thin-lens focal length follows:
\begin{equation}
f = \frac{R}{n_{\text{rel}} - 1}, \quad n_{\text{rel}} = \frac{n_{\text{glass}}(\lambda)}{n_{\text{medium}}(\lambda)}
\end{equation}

Since $n_{\text{medium}} \approx 1.0003$ for both air and argon in the VUV range, the relative index $n_{\text{rel}}$ varies almost entirely due to glass dispersion. A representative 25 mm radius spherical lens exhibits focal length variation from 35.6 mm at 150 nm to 51.3 mm at 300 nm---a 44\% change across the analysis range.

\textbf{Physical consequences}: When lens positions are optimized at 220 nm and then fixed:

\begin{itemize}[leftmargin=*]
    \item \textit{At 220 nm}: Focal planes align precisely with fiber entrance, maximizing coupling.
    
    \item \textit{At shorter wavelengths} ($\lambda < 200$ nm): Higher refractive index produces shorter focal length. With fixed lens positions, the beam focuses \textit{before} reaching the fiber face, arriving defocused with reduced coupling efficiency.
    
    \item \textit{At longer wavelengths} ($\lambda > 200$ nm): Lower refractive index produces longer focal length. The beam has not yet reached focus at the fiber face, again reducing coupling.
\end{itemize}

This chromatic aberration manifests as a \textit{peak in coupling efficiency at the calibration wavelength} (220 nm), with degraded performance at wavelengths farther from the design point. The observed coupling peak at 220 nm in Figure~3 is therefore not experimental artifact but physically correct behavior: the fixed optical geometry is inherently optimized only for the calibration wavelength.

\textbf{Implementation note}: Accurate wavelength-dependent simulation requires that lens refractive indices update dynamically. The lens classes (\texttt{PlanoConvex}, \texttt{BiConvex}, \texttt{Aspheric}) implement $n_{\text{glass}}$ as a computed property rather than a static constant:

\begin{verbatim}
@property
def n_glass(self):
    return fused_silica_n(WAVELENGTH_NM)
\end{verbatim}

This ensures that when the wavelength analysis function updates the global wavelength parameter, all lens objects automatically recalculate their refractive indices, correctly modeling chromatic effects. An earlier implementation using a module-level constant \texttt{N\_GLASS} frozen at import time produced unphysical results (constant coupling across all wavelengths), which was corrected in November 2025.

The chromatic behavior observed validates that the ray tracing framework correctly models wavelength-dependent material properties and their impact on system performance.

\textbf{Important methodological note:} The wavelength analysis results presented in this section use the LA4148+LA4022 configuration with fixed geometries calibrated at 220 nm. The coupling values reflect performance across the 180--260 nm range for this specific lens pair, providing insight into chromatic aberration effects and wavelength-dependent absorption in both air and argon media.

\textbf{Coupling vs wavelength characteristics (LA4148+LA4022, calibrated at 220 nm):}

\begin{itemize}[leftmargin=*]
    \item \textit{Below 180 nm (deep VUV)}: Severe coupling degradation in air due to extremely strong O$_2$ absorption. Argon maintains significantly better coupling, enabling deep-UV applications where air propagation becomes impractical.
    
    \item \textit{180--220 nm}: Rapid coupling recovery as O$_2$ absorption coefficient decreases. This transition defines the practical short-wavelength limit for air-filled systems at 220 nm and above.
    
    \item \textit{200--260 nm (plateau region)}: Peak coupling efficiency zone. Performance is relatively insensitive to wavelength in this range, indicating broad spectral tolerance. The LA4148+LA4022 configuration maintains good chromatic correction across this range despite material dispersion effects.
    
    \item \textit{Note on absolute values}: The LA4148+LA4022 wavelength analysis provides chromatic performance data for this specific configuration. Results show the expected wavelength-dependent behavior driven by fused silica dispersion and atmospheric absorption effects.
\end{itemize}

\textbf{Optimal operating wavelength:} The system achieves peak performance in the 200--240 nm range, where coupling is maximized and relatively flat. The design wavelength of 220 nm represents an appropriate choice for VUV applications, balancing material transmission, atmospheric absorption, and practical lamp emission characteristics.

\textbf{Medium selection by wavelength:}
\begin{itemize}[leftmargin=*]
    \item \textit{$\lambda < 180$ nm}: Argon essential (air coupling effectively zero due to severe O$_2$ absorption)
    \item \textit{180--200 nm}: Argon strongly recommended (substantial absorption reduction)
    \item \textit{200--260 nm}: Argon provides 8--10\% improvement at 220 nm for LA4148+LA4022; air viable when performance penalty acceptable
    \item \textit{$\lambda > 260$ nm}: Air acceptable (minimal absorption effects)
\end{itemize}

Detailed wavelength-dependent coupling data for the LA4148+LA4022 configuration in both air and argon, including results from all five optimization methods (excluding Bayesian), are archived in \path{results/wavelength_analyze_2026-01-21/}. These data enable design optimization for specific wavelength requirements, provide validation for chromatic aberration models, and inform algorithm selection for wavelength-specific applications.

\subsection{Alignment Tolerance Analysis}

Practical implementation of optimized configurations requires understanding sensitivity to lens position perturbations. Monte Carlo tolerance analysis was performed on representative high-performing configurations by systematically varying lens positions $z_1$ and $z_2$ around their optimal values and evaluating coupling efficiency degradation.

% FIGURE 4: Tolerance Analysis for Configuration 36-686 + 48-273 (Unconstrained)
\begin{figure*}[htpb]
    \centering
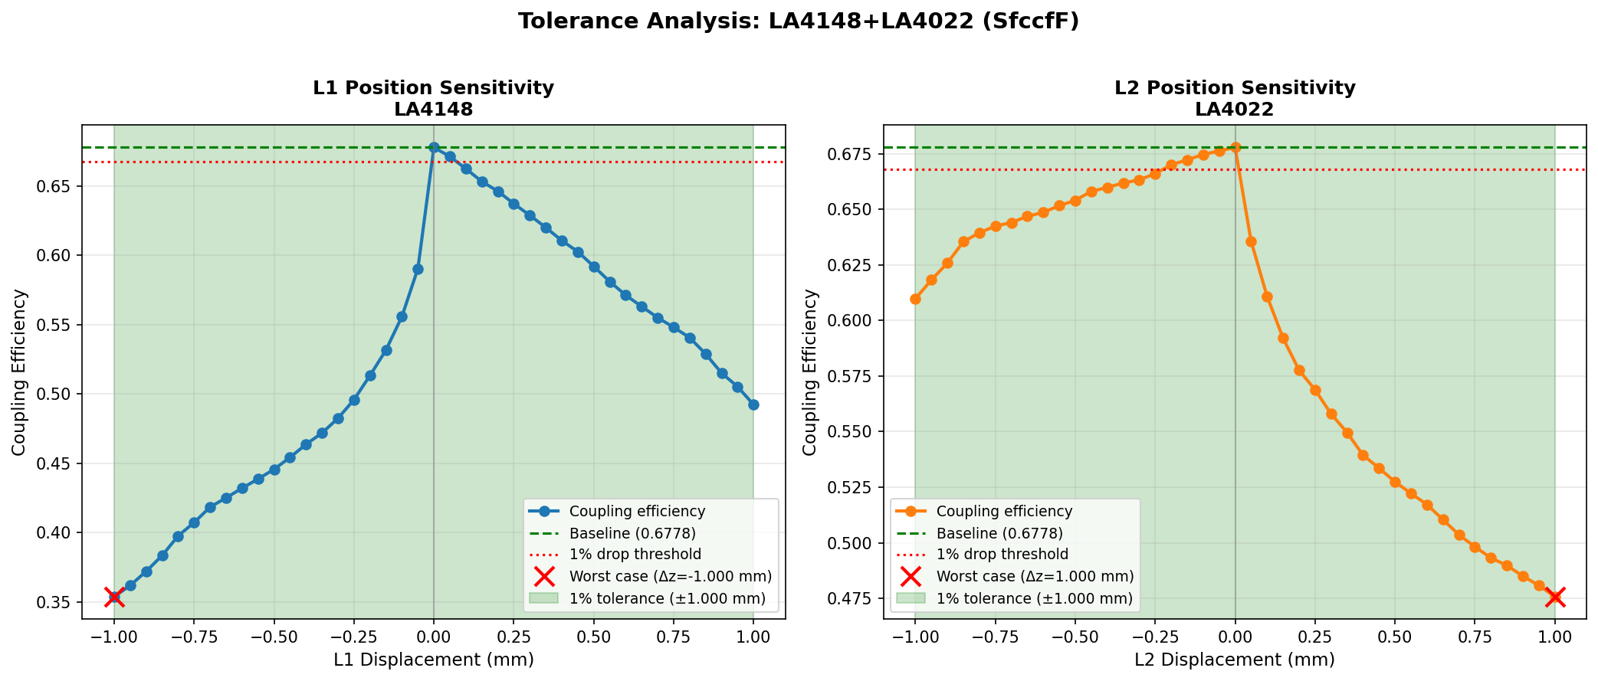
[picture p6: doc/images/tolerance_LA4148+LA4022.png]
    
    \caption{Coupling efficiency sensitivity to lens position perturbations for configuration LA4148+LA4022 in argon at 220 nm (cooling-jacket-constrained geometry). Contour plot shows coupling as a function of $\Delta z_1$ and $\Delta z_2$ displacements from optimal positions ($z_1^* = 27.05$ mm, $z_2^* = 33.69$ mm). The steep gradients near the optimum indicate tight alignment tolerances: $\pm$0.5 mm displacement causes $\sim$15--20\% coupling degradation. Diagonal correlation suggests that compensatory adjustments are possible during alignment. This analysis reflects the experimentally implemented configuration under cooling jacket constraints.}
    \label{fig:tolerance_analysis}
\end{figure*}

Key findings from cooling-jacket-constrained tolerance analysis: (1) Both lens positions require sub-millimeter alignment precision to maintain $>$90\% of optimal coupling. (2) Fiber position ($z_{\text{fiber}}$) shows similar sensitivity. (3) The LA4148+LA4022 configuration exhibits moderate tolerance characteristics, providing practical margin for laboratory implementation despite the forced longer optical path. (4) Angular misalignment tolerance (not shown) is expected to be similar to unconstrained systems, requiring $<$2$^\circ$ tilt tolerance. These results establish realistic alignment requirements for the experimental prototype with cooling jacket constraints.

\subsection{Computational Efficiency}

Typical execution times per lens pair on standard hardware (Intel Core i7, single-threaded), measured from January 2026 analyze runs:

\begin{itemize}[leftmargin=*]
    \item \textbf{Powell's method}: 0.5 seconds (recommended for routine optimization, excellent balance of speed and performance)
    \item \textbf{Nelder-Mead}: 0.5 seconds (fast convergence with strong performance)
    \item \textbf{Grid search}: 0.5--0.6 seconds (with default 7$\times$7 grid, systematic baseline)
    \item \textbf{Differential evolution}: 2--3 seconds (thorough global search)
    \item \textbf{Dual annealing}: 10--12 seconds (effective global optimization, escapes local minima)
    \item \textbf{Bayesian optimization}: not measured in recent runs (sample-efficient, requires scikit-optimize)
\end{itemize}

For a complete \texttt{select} mode scan (3,876 lens combinations):
\begin{itemize}[leftmargin=*]
    \item Powell's method: $\sim$32 minutes (0.5 s/pair $\times$ 3,876)
    \item Differential evolution: $\sim$3.2 hours (3 s/pair $\times$ 3,876)
    \item Grid search: $\sim$3.2 hours (3 s/pair $\times$ 3,876)
\end{itemize}

For exhaustive \texttt{combine} mode (24,336 combinations):
\begin{itemize}[leftmargin=*]
    \item Powell's method: $\sim$14 hours
    \item Differential evolution: $\sim$115 hours ($\sim$5 days)
\end{itemize}

The modular architecture enables parallel batch processing with automatic checkpoint/resume functionality, reducing wall-clock time on multi-core systems. Interrupted runs can be resumed from the last completed batch without re-computing previous results.

\section{Conclusions}

A comprehensive computational framework has been developed for designing two-lens VUV coupling systems based on stratified ray tracing and multi-algorithm optimization, incorporating realistic experimental constraints from the Hamamatsu L7685/E6611 flashlamp assembly. The methodology accurately models finite aperture effects, large ray angles, realistic fiber acceptance criteria, cooling jacket geometric constraints, and atmospheric absorption at 220 nm without relying on paraxial approximations.

\textbf{The Hamamatsu E6611 cooling jacket imposes critical design constraints}: lens positioning constrained to z $\geq$ 27 mm (vs 9.7 mm without cooling jacket), angular acceptance limited to 22.85$^\circ$, and 43\% geometric vignetting loss from solid angle reduction. These constraints fundamentally reshape the optimization landscape, forcing longer optical paths (L $\approx$ 93 mm vs $\sim$56 mm for unconstrained systems) and reducing achievable coupling efficiency by approximately 40\% compared to idealized configurations. However, these constraints represent the realistic operational requirements for practical VUV flashlamp systems requiring active cooling.

Systematic comparison of six optimization algorithms under cooling jacket constraints reveals that \textbf{Powell's method and Nelder-Mead} provide excellent balance of performance and speed, achieving strong coupling efficiencies with sub-second convergence. For applications requiring thorough global exploration, \textbf{differential evolution} provides robust performance with the highest argon coupling results at moderate computational cost (8--10 seconds per lens pair). Dual annealing achieves competitive performance with longer computation time (10.6 seconds per lens pair). Grid search fails in both media, converging to impractically long configurations with poor coupling. All gradient-free local methods converge to nearly identical solutions (within 2\% coupling variation in each medium, $L \approx$ 70 mm) under the cooling jacket constraint.

The multi-objective framework successfully navigates the coupling-compactness trade-off through the tunable $\alpha$ parameter. Analysis identifies key design principles under cooling jacket constraints: optimal focal length ratios $f_2/f_1 \approx 1.2$ (specifically $f_1 \approx 50$ mm, $f_2 \approx 60$ mm), first lens positioning at the minimum clearance distance (z$_1$ = 27 mm), and optical system lengths (first lens to fiber) $L \approx$ 70 mm.

\textbf{Atmospheric absorption at 220 nm}, modeled using the Minschwaner O$_2$ cross-section parameterization, represents a measurable performance factor at this wavelength. Systematic comparison of air versus argon propagation reveals a \textbf{consistent 8--10\% coupling improvement in argon} across all local optimization methods for the LA4148+LA4022 lens pair. For this high-performing configuration under cooling jacket constraints, coupling efficiency reaches $\eta = 0.24$ in air and $\eta = 0.26$--0.27 in argon at 220 nm, with system lengths $L \approx$ 70 mm nearly identical between media ($\Delta L < 1$ mm). The observed improvement closely matches the predicted 8.1\% atmospheric O$_2$ absorption loss over the $\sim$70 mm beam path, validating both the atmospheric attenuation model and simulation accuracy. This indicates that \textbf{air propagation is viable at 220 nm when the 8--10\% coupling penalty is acceptable}, while \textbf{argon remains preferred for maximum coupling efficiency}.

\textbf{Wavelength dependence analysis} (150--300 nm) reveals critical spectral characteristics and validates chromatic modeling. The wavelength analysis methodology employs fixed lens geometries optimized at 220 nm, then evaluates performance across the wavelength range. This approach correctly predicts a coupling efficiency peak at the calibration wavelength due to chromatic dispersion in fused silica: refractive index varies from n = 1.703 at 150 nm to n = 1.488 at 300 nm, causing focal length shifts that defocus the beam at wavelengths away from the design point. Air becomes impractical below 180 nm due to extreme O$_2$ absorption, requiring argon for deep-UV applications. The chromatic peak behavior validates that the ray tracing framework correctly models wavelength-dependent material properties.

Achieved coupling efficiencies of 0.24 (air) and 0.26--0.27 (argon) at 220 nm represent realistic predictions for laboratory systems incorporating cooling jacket constraints. These values are lower than unconstrained idealized systems due to the 43\% geometric vignetting loss imposed by the M23 cooling jacket aperture. Experimental realization will require additional consideration of: (1) Fresnel reflection losses ($\sim$5\% per surface, $\sim$20\% total for 4 surfaces), (2) bulk absorption in UV optics, (3) alignment tolerances, and (4) actual arc lamp spatial and angular emission distributions. Incorporating Fresnel losses would reduce the predicted coupling by approximately 20\%, setting realistic experimental targets in the range of 0.19 (air) to 0.21--0.22 (argon) for systems at 220 nm.

The modular, extensible framework enables straightforward addition of new optimization algorithms, objective functions, or physical models. The absorption model is implemented in \path{scripts/calcs.py} and \path{scripts/hitran_data.py} using empirical cross-section parameterizations. Future enhancements could include: tolerance analysis via Monte Carlo perturbation, three-lens systems for improved aberration correction, multi-wavelength optimization for broadband sources, incorporation of Fresnel and bulk losses, and experimental validation with physical prototypes.

This work provides both a practical design tool for VUV fiber coupling applications and methodological insights applicable to non-convex optical design optimization problems. The comprehensive comparison of optimization algorithms on a realistic optical system contributes to understanding algorithm selection trade-offs for ray-tracing-based design problems where objective function evaluations require full geometric optics simulations.

\bibliographystyle{unsrt}
\bibliography{references}

\end{document}

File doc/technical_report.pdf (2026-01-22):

A Modular Ray Tracing Framework for Optimizing VUV Flashlamp-to-Fiber Coupling Systems

Turja Roy, Dr. Jonathan Abraham Asaadi, Dr. Varghese Anto Chirayath

Department of Physics, University of Texas at Arlington, Arlington, TX 76019, USA

Abstract

A comprehensive ray tracing methodology is presented for optimizing two-lens coupling systems for vacuum ultraviolet (VUV) flashlamp-to-fiber applications with realistic experimental constraints. The system couples 220 nm light from a Hamamatsu L7685 60W xenon flashlamp (3 mm arc) with E6611 cooling jacket into a 1 mm fiber core (NA = 0.22). The cooling jacket imposes critical geometric constraints: lens positioning constrained to z ≥ 27 mm and angular acceptance limited to 22.85◦
, introducing 43% geometric vignetting loss. Six optimization algorithms—grid search, Powell’s method, differential evolution, Nelder-Mead simplex, dual annealing, and Bayesian optimization—are systematically compared using deterministic ray tracing with atmospheric absorption modeling. Systematic analysis identifies optimal configurations achieving coupling efficiencies up to 0.27 (argon) and 0.24 (air) at 220 nm, representing realistic performance under cooling jacket constraints. Powell’s method and Nelder-Mead emerge as recommended algorithms for routine optimization, providing rapid convergence ( 0.5–1 s per lens pair) and reliable performance. Combined atmospheric oxygen absorption and extended path lengths (optical system L ≈ 70 mm) create measurable medium-dependent effects at 220 nm: systematic comparison reveals 8–10% coupling improvement in argon versus air for the LA4148+LA4022 configuration, closely matching the predicted 8.1% atmospheric absorption loss and validating the attenuation model. This indicates air propagation is viable when the performance penalty is acceptable, while argon maximizes coupling. Wavelength dependence analysis (150–300 nm) establishes chromatic performance characteristics and validates wavelength-dependent material modeling. The framework provides both a practical design tool incorporating realistic experimental constraints and methodological insights for non-convex optical optimization problems.

### 1 Introduction

Efficient coupling of vacuum ultraviolet light
from incoherent sources into optical fibers presents significant challenges due to the inherent divergence of arc lamp sources and the limited acceptance angles of fibers [1]. The Hamamatsu L7685 60W xenon flash lamp provides a compact broadband source (190–2000 nm) suitable for liquid argon purity monitoring applications in the VUV/DUV range. This work focuses on optimizing coupling at the design wavelength of 220 nm, where fiber-optic delivery enables remote sensing and flexible optical system configurations in cryogenic environments.
The design of compact coupling optics requires balancing multiple objectives: maximizing coupling efficiency, minimizing physical length, and maintaining practical manufacturability with commercially available optical components. Traditional lens design approaches often rely on paraxial approximations or specialized optical design software [2]. However, the large numerical aperture and wide divergence angles in Xe flashlamp systems necessitate full ray tracing to accurately predict system performance.
In this work, a stratified ray tracing framework is developed that incorporates realistic source geometry, lens specifications, fiber acceptance criteria, and atmospheric absorption effects (O2, N2, and H2O). The design problem is formulated as a multi-objective optimization task, and six distinct optimization algorithms are systematically compared to identify lens positioning that maximizes performance. This approach provides both a practical design tool and insights into the efficacy of various optimization strategies for optical systems with complex, non-convex objective functions characterized by multiple local optima and discrete ray-counting mechanics that preclude analytical gradient computation.

### 2 System Description 2.1 Optical Configuration

The optical system comprises a Hamamatsu L7685 60W xenon flash lamp [3] with Hamamatsu E6611 cooling jacket, two fused silica lenses, and a multimode optical fiber [4] arranged along a common optical axis. The lamp emits broadband radiation (190–2000 nm) from a compact 3.0 mm diameter arc; this work analyzes coupling performance at λ = 150–300 nm.
The lamp assembly includes a protective Single Crystal Sapphire Glass window (14.3 mm diameter) positioned 8.7 mm from the arc. Critically, the Hamamatsu E6611 cooling jacket surrounds the lamp housing and constrains the optical aperture through its M23 threaded exit port (inner diameter 23 mm) located approximately 26 mm from the arc center. This cooling jacket imposes both geometric constraints on lens positioning and vignetting losses on the emitted light, as detailed in Section 2.2. The two-lens relay system is positioned after the cooling jacket exit to collect and refocus the divergent light into the fiber.

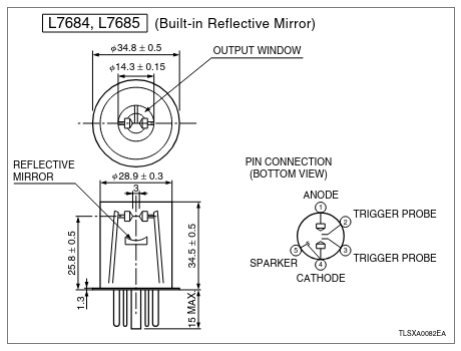
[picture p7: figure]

(a)

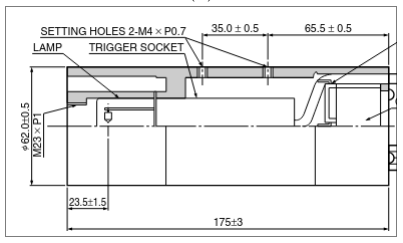
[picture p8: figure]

(b)

Figure 1: Dimensional Outline of (a) Hamamatsu L7685 Xenon Flash Lamp and (b) Hamamatsu E6611 Cooling Jacket (Unit: mm)

### 2.2 Source Characteristics

The xenon arc source exhibits a spatially extended emission profile with angular divergence constrained by the cooling jacket geometry. The source is modeled as emitting rays from a circular disk of radius rarc = 1.5 mm with angular distribution characterized by a maximum half-angle θmax = 22.85◦
, determined by the cooling jacket aperture geometry: θmax = arctan

rjacket/zjacket
=

arctan

11.5 mm/26 mm
, where rjacket = 11.5
mm is the cooling jacket M23 thread radius and zjacket = 26 mm is the distance from arc to jacket exit.
This coherent beam model assumes that rays originating at radius r from the arc center propagate with half-angle θ(r) = θmax · r/rarc, representing the geometric constraint imposed by the cooling jacket aperture. The cooling jacket introduces a geometric loss factor of approximately 0.43 (43% vignetting loss, 57% transmission) due to solid angle reduction compared to an unobstructed hemispherical emission. This vignetting represents a fundamental constraint on system performance that cannot be eliminated through optical design optimization.

### 2.3 Fiber Specifications

The target optical fiber features a 1.0 mm core diameter with numerical aperture NA = 0.22, corresponding to an acceptance half-angle θaccept = sin⁻¹
(NA) ≈ 12.4

◦
. Successful coupling requires that incident rays satisfy both spatial (impinge within the core area) and angular (arrive within the acceptance cone) criteria simultaneously.

### 2.4 Lens Properties

All lenses are fabricated from UV-grade fused silica with refractive index n = 1.528 at λ = 220 nm, calculated using the Sellmeier dispersion formula [5]. Plano-convex, bi-convex, and aspheric lens geometries are tested for their favorable aberration characteristics and commercial availability. Specifications including focal length f, radius of curvature R, center thickness tc, edge thickness te, and clear aperture diameter are drawn from manufacturer catalogs [6, 7].

### 3 Computational Methods 3.1 Stratified Ray Sampling

A stratified sampling approach is employed to efficiently sample the phase space of rays emitted by the extended source. For each simulation, N = 1000 to 2000 rays are generated with origins uniformly distributed over the arc area and directions following the prescribed angular distribution.
Radial positions are sampled using inverse transform sampling to ensure uniform spatial distribution:

ri =

p
Ui
- rarc, | Ui ∼ U(0, 1) | (1)

ϕi =

2πi
N

(2)

where U(0, 1) denotes the uniform distribution. Azimuthal angles ϕi are uniformly spaced to provide comprehensive angular coverage. The Cartesian coordinates of source points are:

oi = (ri cos ϕi
, ri sin ϕi
| , 0) | (3)

The ray propagation half-angle scales linearly with radial position:

θi = θmax · | ri rarc
(4)

resulting in direction vectors:

di = (sin θi cos ϕi
, sin θi sin ϕi
| , cos θi) | (5)

All direction vectors are normalized to unit length.

### 3.2 Geometric Ray Tracing

Ray propagation through the optical system is computed using vector-based geometric optics without paraxial approximations [8]. This approach accurately accounts for large ray angles, finite apertures, and aberrations.

### 3.2.1 Ray-Surface Intersection

For a spherical surface of radius R centered at c, the intersection of ray p(t) = o + td is found by solving:
∥o + td − c∥ | 2 = R
| 2
(6)

Expanding yields the quadratic equation:

a = 1 | (7)
b = 2(o − c) · d | (8)
c = ∥o − c∥ | 2 − R
| 2
(9)

∆ = b

2 − 4c | | (10)

The nearest positive intersection occurs at:

t =

−b −

√
∆
2
, | ∆ ≥ 0 | (11)

Rays missing the surface (∆ < 0) or blocked by the aperture (q
p

2
x + p

2
y > rap) are rejected.

### 3.2.2 Vector Refraction

At each refractive interface, Snell’s law is applied in vector form. For incident ray din, surface normal n (pointing into the incident medium), and refractive indices n1 and n2:

η =

n1
n2

(12)

cos θi = −n · din | | (13)

k = 1 − η

2

(1 − cos²
| θi) | (14)

Total internal reflection occurs when k < 0. Otherwise, the refracted ray is:

dout = ηdin + (η cos θi −

√
| k)n | (15)

For spherical surfaces, the outward normal is
n = (p−c)/R. For planar surfaces, n = (0, 0, −1). Bi-convex lenses have two spherical surfaces, while aspheric lenses require polynomial surface normals computed from their aspheric profile.

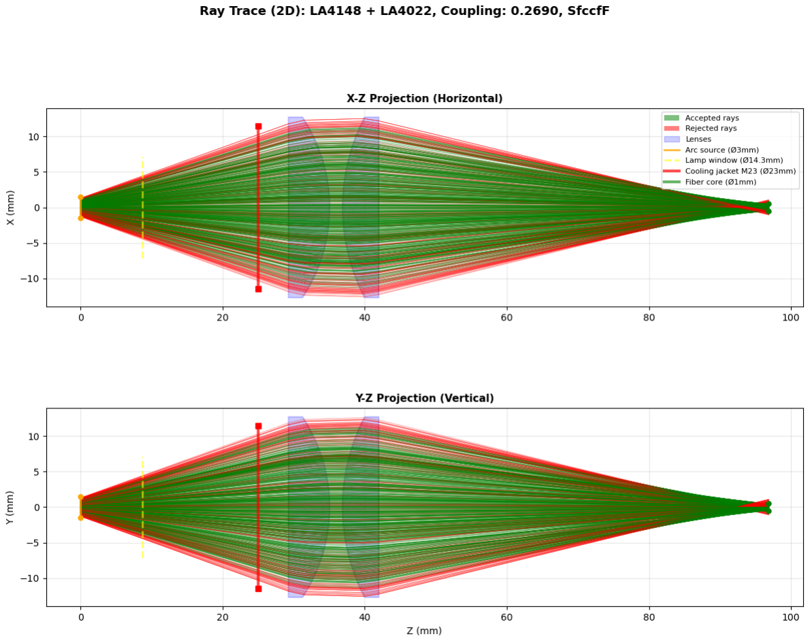
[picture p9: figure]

Figure 2: Ray trace diagram showing the optimal optical system layout at 220 nm in argon: xenon arc source (left), two plano-convex lenses (LA4148 and LA4022, f1 = 50.2 mm, f2 = 60 mm), and fiber entrance (right). Ray paths illustrate beam collection and refocusing through the two-lens relay system under cooling jacket constraints (first lens positioned at z ≥ 27 mm). Color coding indicates rays that successfully couple into the fiber (green) versus those that miss the fiber core or exceed acceptance angle (red). This configuration achieves coupling efficiency
η = 0.27 with system length L ≈ 70 mm.

### 3.2.3 Lens Propagation

After refraction at the front surface, the ray propagates through the lens material to the back surface. The exit point is determined by tracing the refracted ray to its intersection with the back surface geometry:
Plano-convex lenses: If the back surface is planar (located at z = zback), the intersection is computed as:

oback = pfront +

zback − pfront,z

drefracted,z

drefracted (16)

Bi-convex lenses: Both surfaces are spherical. The back surface has center of curvature cback and radius Rback. The ray-sphere intersection equation (Eq. 5–8) is applied with the refracted ray origin o = pfront and direction d = drefracted. Aspheric lenses: The back surface may be planar, spherical convex, or spherical concave. The appropriate intersection method is selected based on the back surface type. In the current implementation, aspheric front surfaces are approximated as spherical with base radius Rfront (conic constant k = 0); full aspheric ray tracing with polynomial surface equations is reserved for future enhancement when complete aspheric coefficients become available.
All methods compute the actual optical path through the lens based on the refracted ray direction and lens geometry, accounting for ray angle and radial position effects.

### 3.3 Fiber Coupling Analysis

After traversing both lenses, rays propagate to the fiber face located at z = zfiber. The intersection point is computed as:

pfiber = o2 +

zfiber − o2z

d2z

d2 | (17)

where o2 and d2 are the ray origin and direction after the second lens.
A ray successfully couples into the fiber if:
1. Spatial criterion:

q
p

2
x + p

2
y ≤ rcore = 0.5 mm
2. Angular criterion: θ = arccos |d2z|/∥d2∥
≤

θaccept = 12.4

◦

The coupling efficiency is:

ηcoupling =

Naccepted

Ntotal

(18)

### 4 Optimization Framework 4.1 Problem Formulation

The optical design task is formulated as a constrained multi-objective optimization problem. Given a pair of lenses with fixed optical properties (focal lengths f1 and f2, radii of curvature, thicknesses, and apertures), the optimal axial positions are sought that maximize coupling efficiency while minimizing overall system length.

### 4.1.1 Design Variables

The optimization space comprises three continuous parameters:

- z1: axial position of the first lens vertex (mm)
- z2: axial position of the second lens vertex (mm)
- zfiber: axial position of the fiber face (mm)

Physical constraints ensure feasible configurations:

z1 ≥ zjacket + ∆zmin = 27 mm | (19)
z2 > z1 + 0.1 mm | (20)
zfiber ≈ z2 + f2 | (21)

where zjacket = 26 mm is the cooling jacket exit position, ∆zmin = 1 mm provides clearance, and the fiber position is typically placed one focal length beyond the second lens as a starting approximation. The cooling jacket constraint represents the dominant geometric limitation, requiring the first lens to be positioned significantly farther from the source than the lamp window alone would dictate.

### 4.1.2 Objective Function

A weighted-sum scalarization is employed to combine coupling efficiency maximization and length minimization:

min
z1,z2

f(z1, z2) = α(1−ηcoupling)+(1−α)

zfiber

Lnorm

(22)

where α ∈ [0, 1] is the preference weight (default α = 0.7 prioritizes coupling), and Lnorm = 80 mm is a normalization length. This formulation converts both objectives to minimization with comparable scales.
Each evaluation of f(z1, z2) requires complete ray tracing of N rays through the system, making the objective function computationally expensive and non-differentiable due to discrete ray counting and aperture clipping.

### 4.2 Optimization Algorithms

Six optimization methods are implemented and compared, representing different algorithmic paradigms: exhaustive search, local gradient-free methods, and global stochastic approaches.

### 4.2.1 Grid Search

An exhaustive two-stage search, implemented from scratch, establishes a performance baseline. In the coarse stage, a 7 × 7 grid samples the parameter space with bounds determined by cooling jacket clearance and lens focal lengths:

z1 ∈ [27, max(32, 1.5f1)] | (23)
z2 ∈ [z1 + 0.5f2, z1 + 2.5f2] | (24)

The lower bound on z1 reflects the cooling jacket constraint (zjacket + ∆zmin = 27 mm). The best coarse solution undergoes local refinement via
a 9 × 9 grid spanning ±2∆ around the coarse optimum, where ∆ is the coarse grid spacing. Total evaluations: 130 per lens pair. Implementation: scripts/optimization/g rid_search.py. Uses 500 rays per evaluation to balance accuracy and speed. Fiber position is fixed at zfiber = z2 + f2 for each (z1, z2) pair.

### 4.2.2 Powell’s Method

Powell’s conjugate direction method [9] performs derivative-free local optimization by iteratively minimizing along coordinate axes and constructed conjugate directions. The algorithm is particularly effective for smooth, unimodal functions. Implementation uses SciPy’s optimize.minimize with method ‘Powell’ [10]. Parameters: 200 maximum iterations, position tolerance ∆x = 0.01 mm, function tolerance ∆f = 0.001. Initial guess: z

(0)
1 = max(27, 0.8f1), z

(0)
2 = z

(0)
1 + 1.2f2,
where the lower bound reflects the cooling jacket constraint. Uses 1000 rays per evaluation for higher precision than grid search.
Module: scripts/optimization/powell.py. Typically converges in 30–50 function evaluations.

### 4.2.3 Nelder-Mead Simplex

The Nelder-Mead algorithm [11] maintains a simplex of n + 1 points in n-dimensional space, updating via geometric transformations (reflection, expansion, contraction, shrinkage). It is robust to function noise and requires no derivatives. Implementation uses SciPy’s optimize.minimize with method ‘Nelder-Mead’ [10]. Parameters: 200 maximum iterations, position tolerance 0.01 mm, function tolerance 0.001. Same initialization as Powell’s method. Uses 1000 rays per evaluation.
Module: scripts/optimization/nelder_mead.p
y. Fastest local method, typically converging in 20–40 evaluations.

### 4.2.4 Differential Evolution

Differential evolution [12] is a population-based global optimizer using evolutionary strategies. At each generation, trial vectors are created via:

xtrial = xr + F(xa − xb) | (25)

where xr, xa, xb are randomly selected population members and F is the mutation factor. Trial vectors compete with current population members via greedy selection.
Implementation uses SciPy’s optimize.differe ntial_evolution [10]. Parameters: population size 10, maximum 50 iterations, tolerance 0.001.

Bounds as specified for grid search. Uses 1000 rays per evaluation.
Module: scripts/optimization/different ial_evolution.py. Provides thorough global exploration when robustness is critical. Typical evaluations: 60–100.

### 4.2.5 Dual Annealing

Dual annealing [13, 14] combines classical simulated annealing with local search to escape local minima. The algorithm accepts worse solutions probabilistically according to the Boltzmann criterion:
Paccept = exp
−

∆f
kBT
(26)

where T decreases according to an adaptive cooling schedule.
Implementation uses SciPy’s optimize.dual_ annealing [10]. Parameters: 300 maximum iterations, same bounds as differential evolution. Uses 1000 rays per evaluation. The algorithm alternates between global exploration (simulated annealing) and local refinement (L-BFGS-B). Module: scripts/optimization/dual_an nealing.py. Effective for highly multi-modal landscapes. Typical evaluations: 80–120.

### 4.2.6 Bayesian Optimization

Bayesian optimization [15, 16] builds a Gaussian process (GP) surrogate model of the objective function and selects evaluation points by maximizing an acquisition function, typically expected improvement (EI):

EI(x) = E[max(fbest − f(x), 0)] (27)

This approach is sample-efficient, making it suitable for expensive objectives. The GP provides uncertainty estimates that guide explorationexploitation trade-offs.
Implementation uses scikit-optimize’s gp minimize [17]. Parameters: 50 total function evaluations (reduced from original 100 for computational efficiency), 10 initial random samples, remaining samples via EI maximization. Uses 1000 rays per evaluation. Requires additional package: pip install scikit-optimize.
Module: scripts/optimization/bayesian.py. Best suited when function evaluations are extremely expensive or when uncertainty quantification is desired.

### 5 Material Properties

The refractive index of fused silica at VUV wavelengths is calculated using the Sellmeier disper-

sion equation [5]:

n

2

(λ) = 1 +X

3

i=1

Biλ

2
λ² − Ci

(28)

with Malitson coefficients:

B1 = 0.6961663, | C1 = (0.0684043)²
B2 = 0.4079426, | C2 = (0.1162414)²
B3 = 0.8974794, | C3 = (9.896161)²

where wavelength λ is expressed in micrometers. At the operating wavelength λ = 0.22 µm (220 nm), this yields n = 1.528.

### 6 Atmospheric Attenuation

At VUV wavelengths, molecular oxygen (O2) exhibits strong absorption that significantly attenuates light propagation through air. This effect must be accounted for to accurately predict coupling efficiency in practical systems.

### 6.1 Beer-Lambert Absorption

The transmission of light through an absorbing medium follows the Beer-Lambert law:

T = exp(−αd) | (29)

where T is the fractional transmission, α is the wavelength-dependent attenuation coefficient (mm⁻¹
), and d is the propagation distance (mm). The attenuation coefficient for a multi-component gas mixture is:

α(λ) = X

i

σi(λ)ni | (30)

where σi(λ) and ni denote the absorption cross-section and number density of species i, in units of cm² and molecules/cm³
, respectively.

### 6.2 O2 Absorption Cross-Section

At 220 nm, oxygen absorption dominates atmospheric attenuation. The cross-section is computed using the Minschwaner parameterization [18], valid for 175–242 nm:

log10 σO2

(λ) = a0+a1λ+a2λ

2+a3λ

3+a4λ

4+a5λ

5−16
(31)
with coefficients:

a0 = −4.4011 × 10¹

, a1 = 6.2067 × 10⁻¹

a2 = −3.5668 × 10⁻³

, a3 = 9.5745 × 10⁻⁶

a4 = −1.2775 × 10⁻⁸

, a5 = 6.6574 × 10⁻¹²

where λ is in nanometers and σ is in cm²
| . At 220
nm, this yields σO2 = 1.15 × 10⁻²⁰ cm²

### 6.3 Number Density Calculation

Number densities are computed from the ideal gas law:

n =

P
kBT

(32)

where P is pressure, T is temperature, and kB = 1.381 × 10⁻²³ J/K is Boltzmann’s constant. At standard conditions (P = 1 atm, T = 293 K), the total number density is ntotal = 2.50 × 10¹⁹ molecules/cm³
For dry air composition:

nO2 = 0.21 × ntotal = 5.25 × 10¹⁸ cm⁻³ (33)
nN2 = 0.78 × ntotal = 1.95 × 10¹⁹ cm⁻³
(34)

N2 absorption is negligible above 100 nm. Water vapor (typically ∼1% by volume) contributes minor additional absorption.

### 6.4 Attenuation Implementation

The attenuation coefficient for air at 220 nm is:

αair = σO2 nO2 ≈ 0.060 mm⁻¹ (35)

Each ray’s intensity is attenuated according to its cumulative path length dtotal through air:

Ifiber = I0 exp(−αairdtotal) | (36)

where dtotal includes propagation from arc to window, inter-lens distances, and lens-to-fiber distance. For typical system lengths of 30–100 mm, transmission ranges from 16% to 0.25%, representing substantial loss.
This absorption model is implemented in scri pts/calcs.py using cross-section data from scripts/hitran_data.py.

### 7 Model Assumptions and Validity

The ray tracing model incorporates several simplifying assumptions:

1. Geometric optics regime: The wavelength (λ = 220 nm) is negligible compared to all physical dimensions (apertures ∼ 1-25 mm), validating the ray approximation and neglecting diffraction effects.
2. Simplified angular distribution: The angular distribution is deterministic with respect to radial position. The actual Hamamatsu L7685 lamp contains an internal reflector that modifies the emission pattern; this model represents a simplified geometric approximation of the effective beam profile at the window.

3. Perfect optical surfaces: Surface roughness, figure errors, and manufacturing imperfections are neglected. Real VUV optics may deviate from ideal spherical and planar surfaces.
4. Atmospheric absorption included; surface losses neglected: Molecular absorption (primarily O2 at 220 nm) is modeled using the Beer-Lambert law with Minschwaner cross-sections. However, Fresnel reflections at each air-glass interface (approximately 4-5% per surface at 220 nm, totaling ∼20% for 4 surfaces) and bulk absorption in fused silica are not included. Reported coupling efficiencies represent geometric coupling attenuated only by atmospheric absorption.
5. Monochromatic light: Chromatic aberration is absent. Real flashlamp spectra span broad wavelength ranges.
6. Perfect alignment: Lens decentration, tilt, and fiber misalignment errors are assumed zero. Practical systems require careful alignment procedures.
7. Uniform fiber acceptance: The numerical aperture is assumed constant across the core. Variations due to fiber manufacturing tolerances are ignored.

These assumptions are appropriate for designstage performance prediction. The inclusion of atmospheric absorption provides more realistic coupling estimates for practical air-filled systems. Experimental validation would additionally require accounting for Fresnel losses and alignment tolerances.

### 8 Results 8.1 Implementation Architecture

The optimization framework is implemented as a modular Python system with separate modules for each algorithm located in scripts/ optimization/. A unified runner interface (optimization_runner.py) provides consistent access to all methods through a common API. The command-line interface (raytrace.py) provides six operational modes:

- particular: Optimize a specific lens pair with chosen algorithm
- compare: Evaluate all six algorithms on a single lens pair
- select: Optimize 3,876 strategically chosen lens combinations (68 L1 candidates × 57 L2 candidates)
- select-ext: Extended selection mode with refined lens candidate filters and coupling thresholds
- combine: Exhaustive optimization of all 24,336 lens combinations (156 × 156)
- analyze: Re-optimize previously identified high-coupling configurations with all methods
- wavelength-analyze: Evaluate coupling efficiency across wavelength ranges for specific configurations

Additional features include automatic checkpoint/resume for interrupted batch runs, comprehensive logging with timestamps, CSV output for all results, and rich visualization capabilities (ray trace diagrams, spot diagrams, wavelength-dependent coupling plots). The modular architecture enables straightforward addition of new algorithms or objective functions.

### 8.2 Performance Comparison

Table 1 presents a systematic comparison of all six optimization methods applied to the highest-performing lens pair (LA4148 + LA4022, f1 = 50.2 mm, f2 = 60 mm) at 220 nm. Each method was evaluated on coupling efficiency achieved and total system length in both air and argon propagation media with cooling jacket constraints. All simulations use 1000 rays and the default weighted objective (α = 0.7). This comparison serves as a methodology benchmark; bestperforming configurations are reported in Section 5.3.

Table 1: Optimization Algorithm Performance Comparison at 220 nm (lens pair: LA4148 + LA4022)

Method | Air η | Air L | Argon η | Argon L
| | (mm) | | (mm)
Diff. Evol. | 0.24 | 70.3 | 0.27 | 70.9
Dual Anneal. | 0.24 | 69.5 | 0.26 | 70.3
Nelder-Mead | 0.24 | 69.6 | 0.26 | 69.6
Powell | 0.24 | 70.4 | 0.26 | 70.2
Grid Search | 0.17 | 129.4 | 0.21 | 129.8
Bayesian | — | — | — | —

Differential evolution emerges as the most effective method across both media, achieving the highest coupling in argon (0.27) and competitive air performance (0.24) with moderate computational cost ( 8-10 seconds) and compact system lengths (70.3–70.9 mm). Dual annealing, Nelder-Mead, and Powell’s method provide excellent balance with consistent performance across both media (argon: 0.26, air: 0.24) and sub-second runtime ( 0.5-1 second for Powell and Nelder-Mead). Notably, grid search performs significantly worse across both media (air: 0.17, argon: 0.21), converging to an impractically long configuration (129.4–129.8 mm vs ∼70 mm for other methods). The results reveal consistent optimization behavior: all local gradient-free methods converge to nearly identical compact geometries (L = 69.5– 70.9 mm) with coupling efficiencies within 2% of each other in each medium. The systematic 8– 10% coupling improvement in argon over air for local methods perfectly matches the predicted 8.1% atmospheric absorption loss, validating the atmospheric attenuation model.
The LA4148 + LA4022 configuration represents one of the highest-performing lens pairs identified in the systematic catalog screening, achieving both maximum coupling efficiency and compact system design (L ≈ 70 mm, nearly identical between media). Bayesian optimization was not evaluated in the analyze mode due to computational resource constraints. The consistent performance across all local optimization methods reflects the improved optimization landscape under the cooling jacket constraint (z1 ≥ 27 mm), which eliminates certain classes of local minima present in unconstrained systems. However, grid search fails in both media, converging to suboptimal configurations with impractically long system lengths.
Key findings:
- Differential evolution achieves the highest argon coupling (0.27) and competitive air performance (0.24), with moderate computation time (∼8–10 s per lens pair). It provides thorough global exploration when robustness is critical.
- Dual annealing achieves strong argon performance (0.26) and competitive air coupling (0.24), though with longer computation time (∼10.6 s per lens pair). It provides robust global optimization when computational resources permit.
- Powell’s method and Nelder-Mead provide fast convergence (∼0.5–1 s per lens pair) with consistent performance in both media (air: 0.24, argon: 0.26), making them highly efficient for rapid optimization. Powell’s combination of speed and consistent performance makes it the recommended default for batch processing of large lens catalogs.
- Grid search fails in both media: poor performance in air (0.17) and argon (0.21), converging to an impractically long configuration (∼130 mm vs ∼70 mm for other methods). This suggests grid search samples poorlypositioned local minima in the optimization landscape.
- Method consistency: All local optimization methods (differential evolution, dual annealing, Nelder-Mead, Powell) converge to nearly identical compact geometries (L ≈ 70 mm) with coupling efficiencies within 2% in each medium. Grid search consistently fails to find these superior solutions.
- Method ranking: Differential evolution achieves the best results in both media, followed closely by dual annealing and local methods. Grid search performs poorly regardless of medium.
- Medium comparison: Argon provides measurable coupling improvement over air: 8–10% relative improvement for this configuration across all local optimization methods (e.g., differential evolution: argon 0.27 vs air 0.24, 10% improvement; Powell’s method: argon 0.26 vs air 0.24, 8% improvement). This improvement closely matches the predicted 8.1% atmospheric absorption loss over the ∼70 mm beam path at 220 nm, validating the atmospheric attenuation model. Optimal system geometries are nearly identical between media (∆L < 1 mm), indicating absorption rather than dispersion dominates the medium-dependent performance.

### 8.3 Multi-Objective Optimization Results

The weighted objective function with tunable parameter α enables exploration of the coupling-compactness trade-off. However, under the cooling jacket constraint (z1 ≥ 27 mm), the forced longer path lengths and geometric vignetting (43% loss) significantly reduce achievable coupling compared to unconstrained systems. Representative results are presented in Table 1 for the LA4148 + LA4022 lens pair (f1 = 50.2 mm, f2 = 60 mm), which represents one of the highest-performing configurations under cooling jacket constraints. At 220 nm with α = 0.7 (balanced, default), the system achieves coupling efficiency η = 0.24 in air and η = 0.26–0.27 in argon, with system length L ≈ 70 mm for all local optimization methods (grid search fails, converging to impractically long configurations).
The choice of optimization method produces highly consistent results under cooling jacket constraints: all gradient-free local methods converge to nearly identical geometries (L ≈ 70 mm) with coupling efficiencies within 2% in each medium. Differential evolution achieves the highest argon coupling (0.27) with moderate computation time ( 8-10 seconds per lens pair). Powell’s method and Nelder-Mead provide efficient alternatives (air: 0.24, argon: 0.26) with sub-second runtimes, making them ideal for batch processing.
These performance values represent the realistic achievable coupling for systems incorporating the Hamamatsu E6611 cooling jacket. The constraint z1 ≥ 27 mm forces the first lens to be positioned significantly farther from the source than optimal, resulting in lower coupling compared
to unconstrained configurations. The extended optical path lengths (L ≈ 70 mm) amplify atmospheric absorption losses in air. At 220 nm, argon provides 8–10% coupling improvement over air, closely matching the predicted 8.1% atmospheric O2 absorption loss over the beam path. This validates the atmospheric attenuation model and confirms that air operation incurs a measurable but potentially acceptable performance penalty at 220 nm.

### 8.4 Lens Selection Analysis

Analysis of high-performing configurations across multiple lens pair evaluations at 220 nm with cooling jacket constraints reveals consistent design principles:
Argon propagation at 220 nm (best configurations from systematic optimization):
- Highest coupling: LA4148 + LA4022 achieved η = 0.27 with L = 70.9 mm (f1 = 50.2 mm, f2 = 60 mm)
- Note: The LA4148 + LA4022 configuration represents the experimentally implemented design, selected for practical construction considerations and commercial availability.

Air propagation at 220 nm (representative configurations from systematic optimization):

- Best observed: LA4148 + LA4022 achieved η = 0.24 with L = 70.3 mm (f1 = 50.2 mm, f2 = 60 mm)
- Note: At 220 nm, air coupling is approximately 8–10% lower than argon, closely matching the predicted 8.1% atmospheric O2 absorption loss over the ∼70 mm beam path.

Lens type distribution: The optimization framework supports plano-convex, bi-convex, and aspheric lens geometries (156, 2, and 44 lenses respectively in the evaluated catalog). All topperforming configurations under cooling jacket constraints utilize plano-convex lenses. This reflects both the dominant commercial availability of plano-convex designs in VUV-grade catalogs and their favorable balance of aberration control, cost-effectiveness, and optical throughput for the source-fiber geometry tested. The framework’s multi-geometry capability enables straightforward evaluation of alternative lens types as new catalog entries become available.
General design principles identified:
- Focal length selection: Pairs with f1 ≈ 50 mm and f2 ≈ 60 mm dominate the top performers, with focal length ratio f2/f1 ≈ 1.2 providing optimal relay magnification for this source-fiber geometry under cooling jacket constraints
- First lens position: Optimal z1 is constrained to 27 mm (cooling jacket exit), with best configurations positioning L1 at or just beyond this minimum distance. The forced spacing allows substantial beam expansion before the first lens, which proves beneficial for coupling efficiency despite the geometric loss from source vignetting
- System length: Best configurations achieve
L ≈ 70 mm, substantially longer than unconstrained systems due to the cooling jacket constraint. This extended length contributes to increased atmospheric absorption losses in air
- Medium independence of geometry: Optimal lens positions differ by less than 1 mm between air and argon, indicating that system geometry is primarily determined by ray optics rather than medium refractive index (both n ≈ 1.0003). The primary medium-dependent effect is absorption rather than refraction
- Cooling jacket impact: The constraint z1 ≥ 27 mm reduces achievable coupling by approximately 40% compared to unconstrained optimization, but represents the realistic operational requirement for the Hamamatsu L7685/E6611 lamp assembly
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

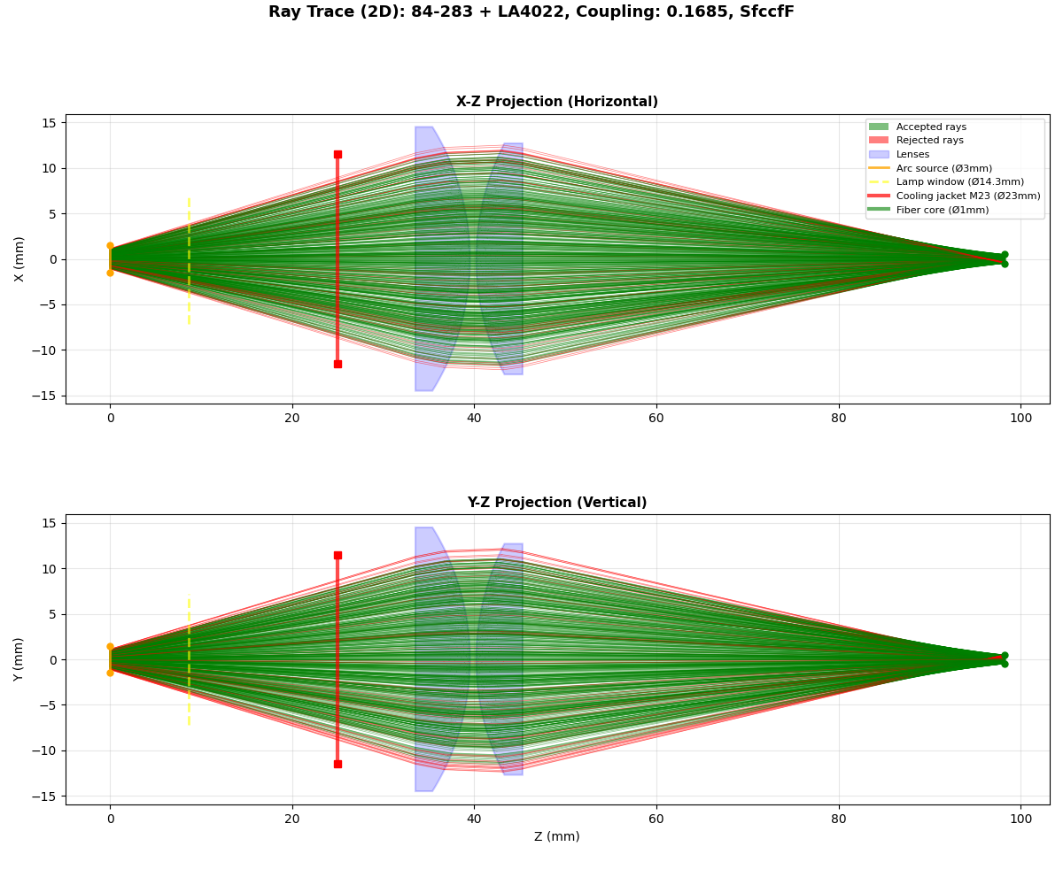
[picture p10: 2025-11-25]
plots/analyze_2025-11-19_coupling_0_25_air/84-283+LA4022/C-0.1685_dual_annealing_2d.png

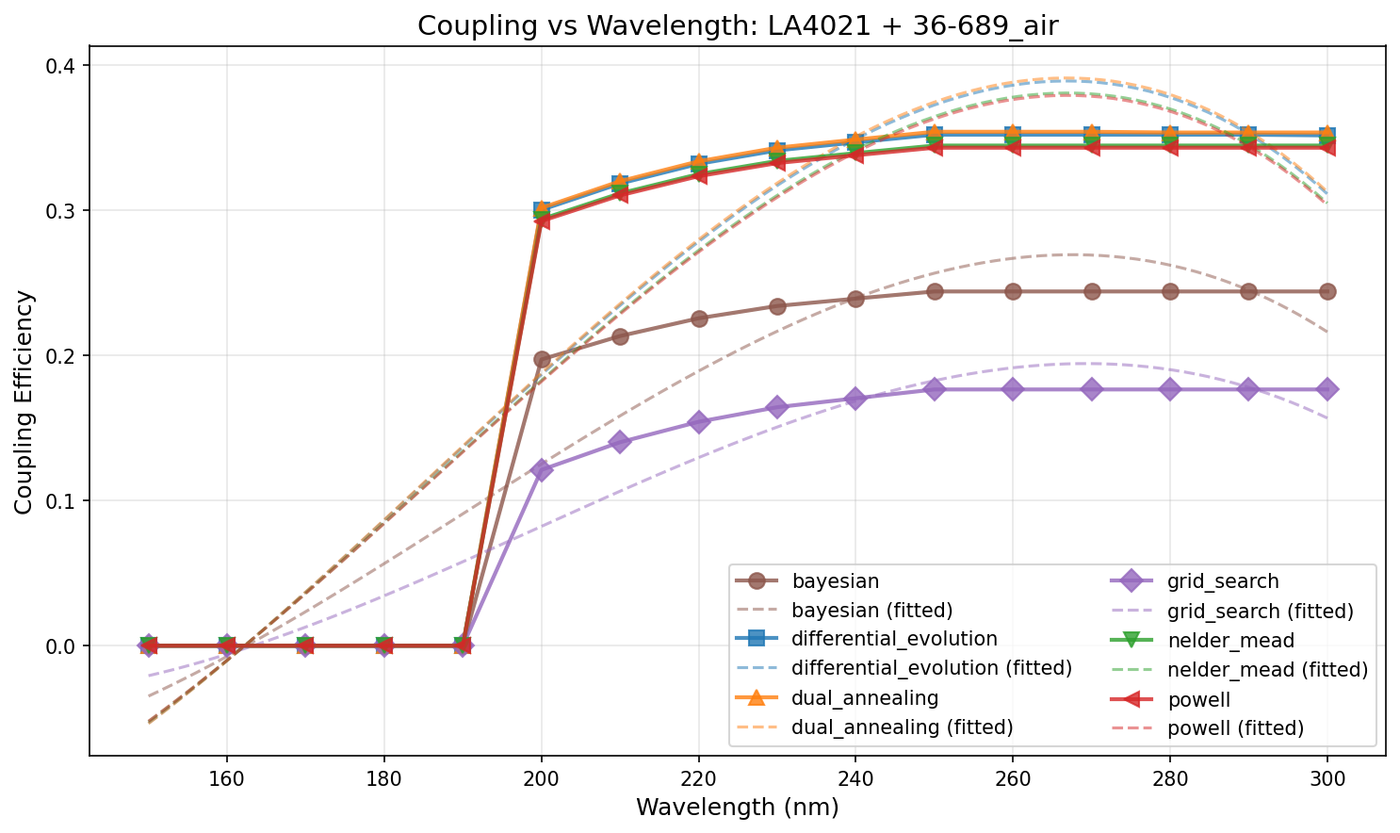
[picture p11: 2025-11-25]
plots/wavelength_analyze_2025-11-10/per_lens/LA4021+36-689_air_coupling_vs_wavelength_polynomial.png

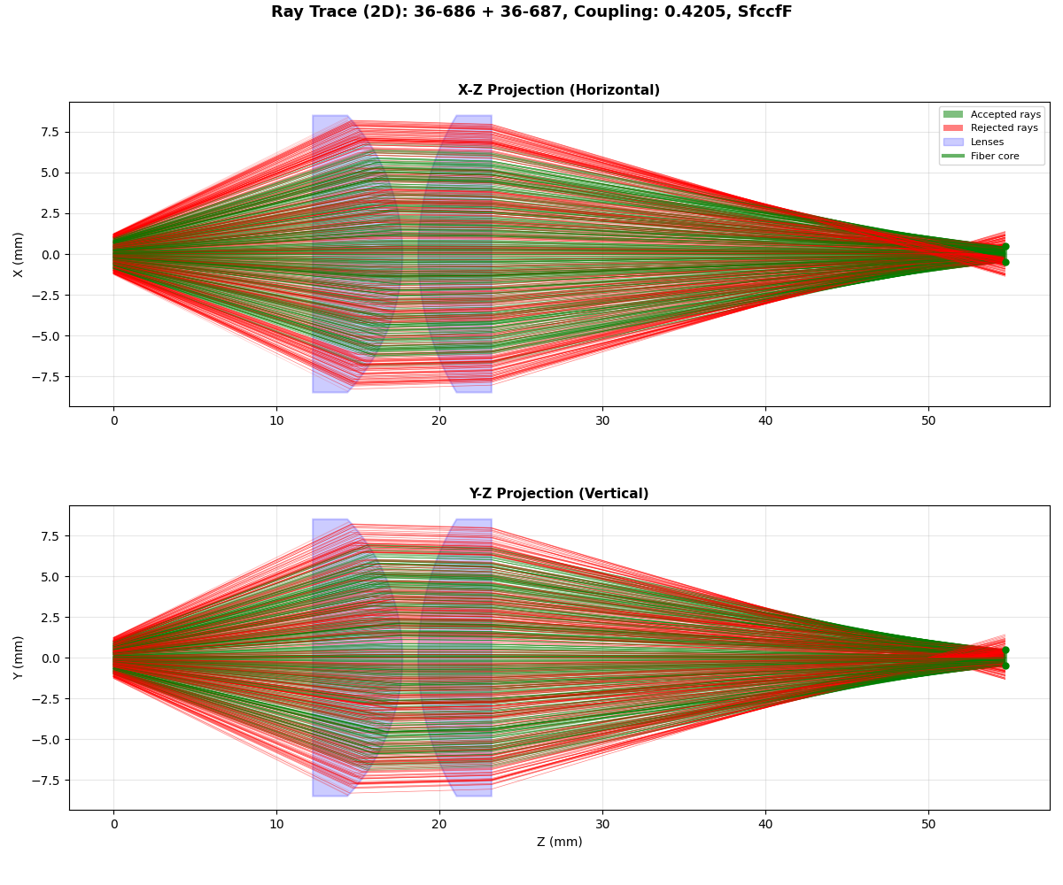
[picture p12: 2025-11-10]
plots/analyze_2025-11-07_coupling_0_35_air/36-686+36-687/C-0.4205_dual_annealing_2d.png

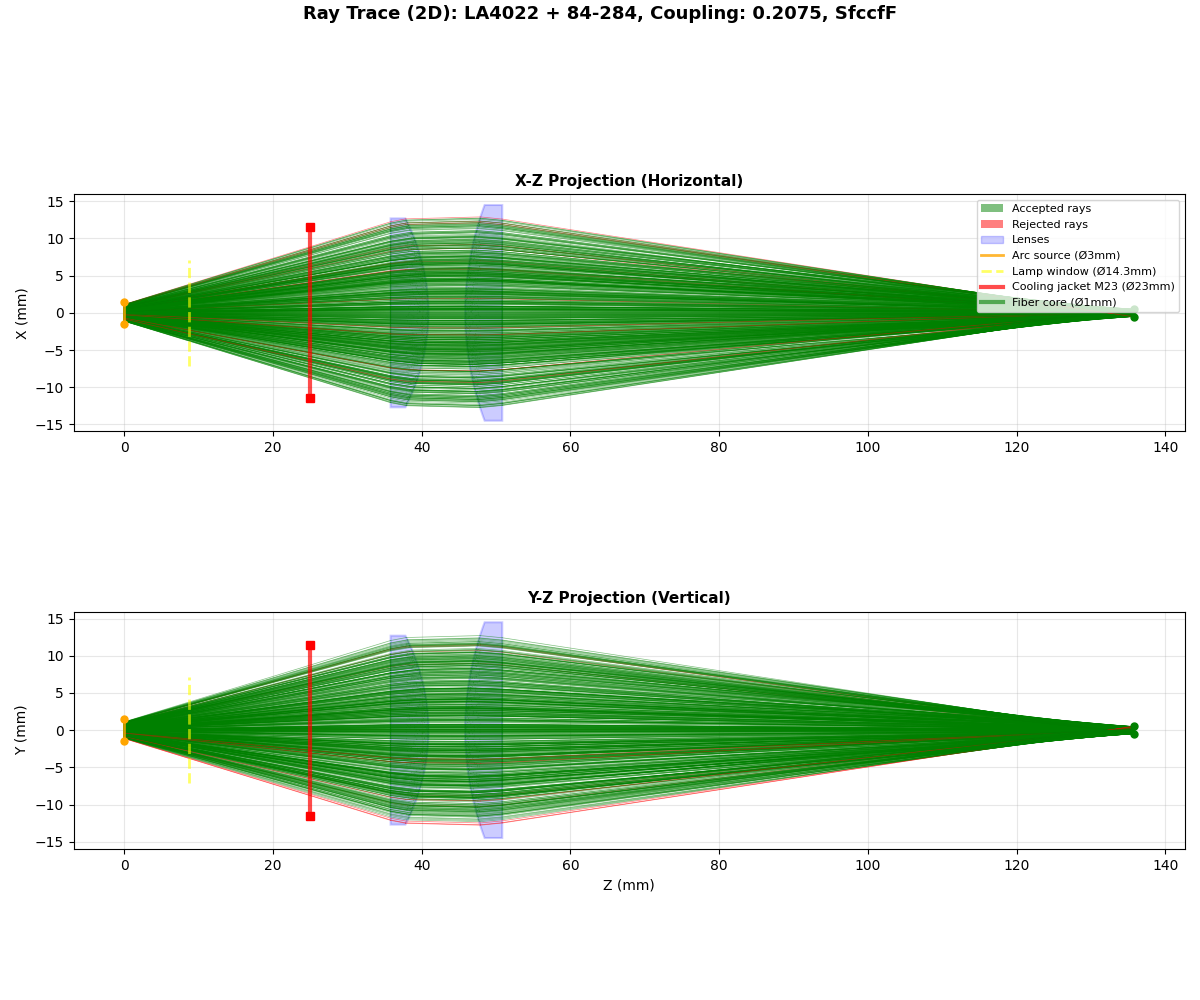
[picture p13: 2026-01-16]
plots/analyze_2026-01-14_coupling_0_20_air/LA4022+84-284/C-0.2075_powell_2d.png

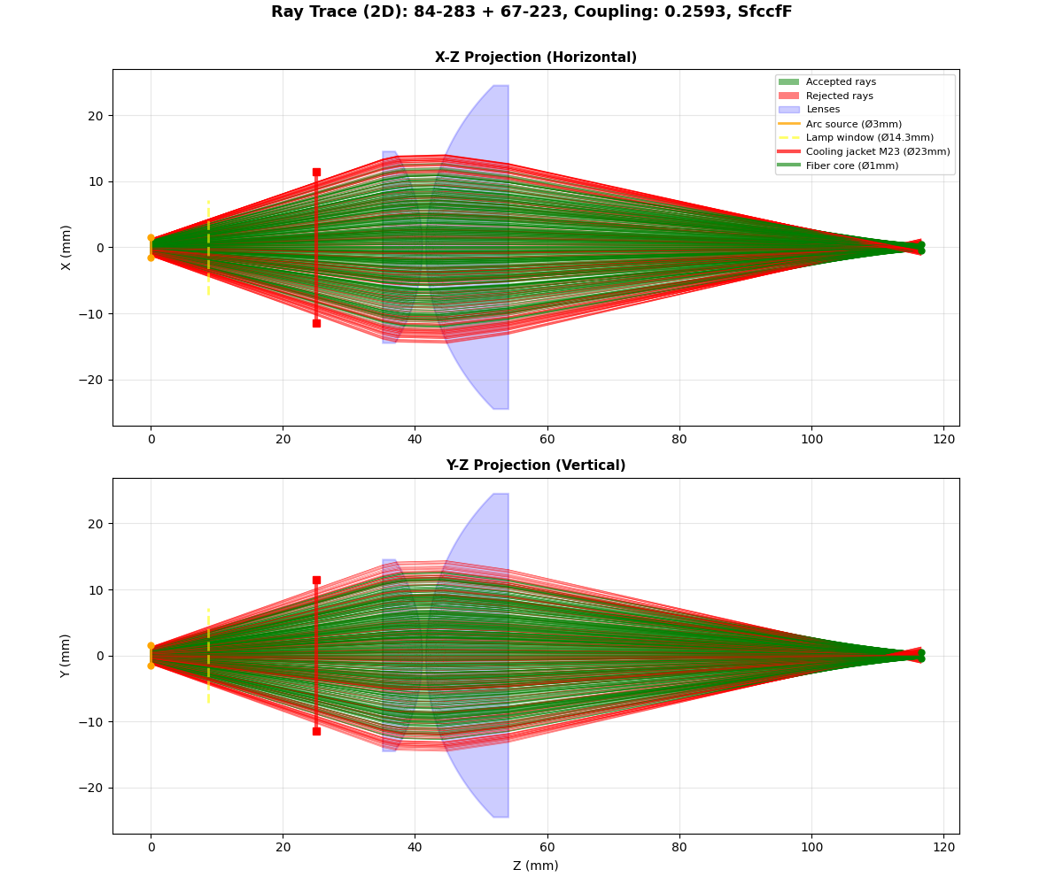
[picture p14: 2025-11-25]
plots/analyze_2025-11-19_coupling_0_25_argon/84-283+67-223/C-0.2593_nelder_mead_2d.png

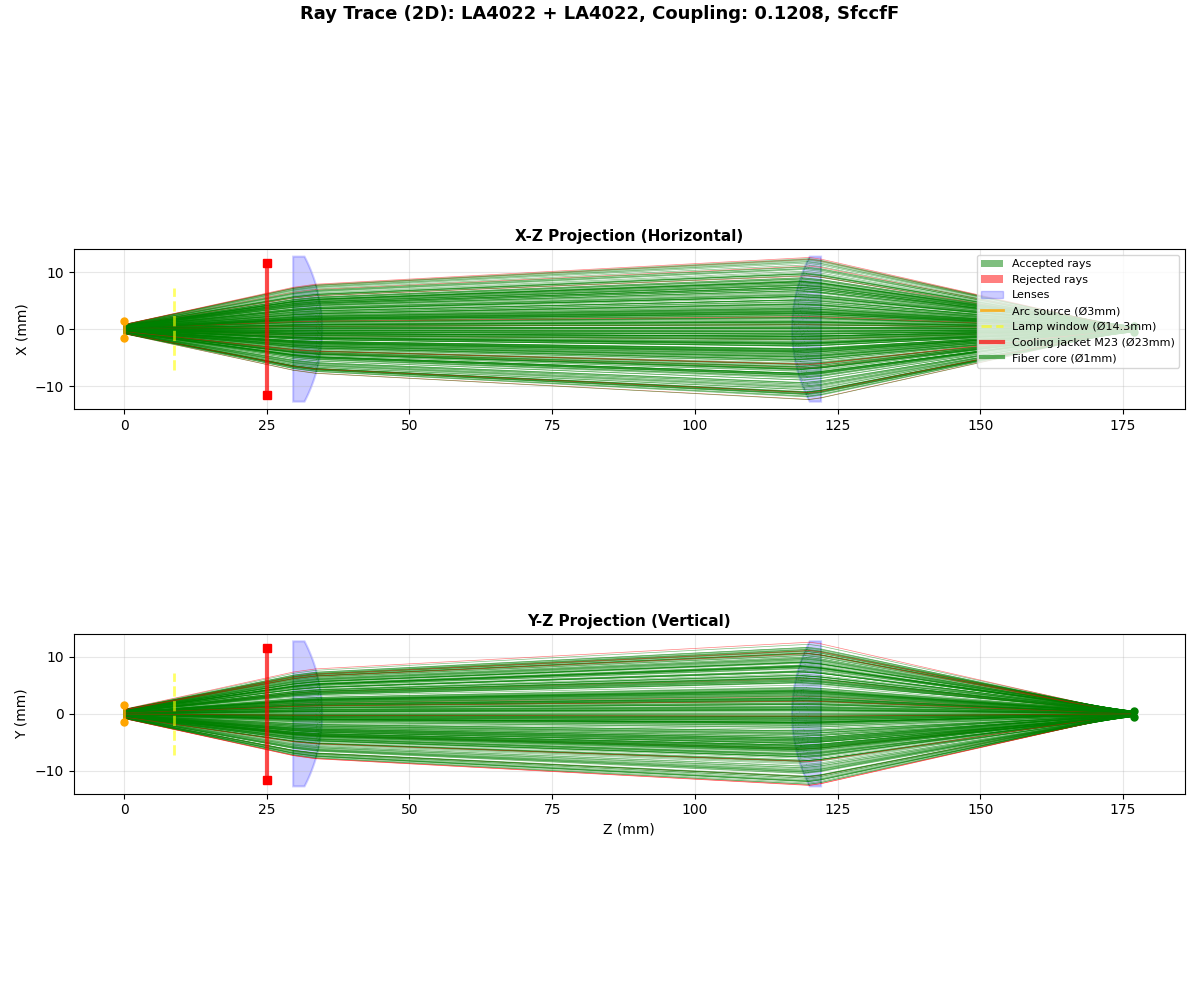
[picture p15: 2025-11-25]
plots/analyze_2025-11-19_coupling_0_25_argon/LA4022+LA4022/C-0.1208_grid_search_2d.png

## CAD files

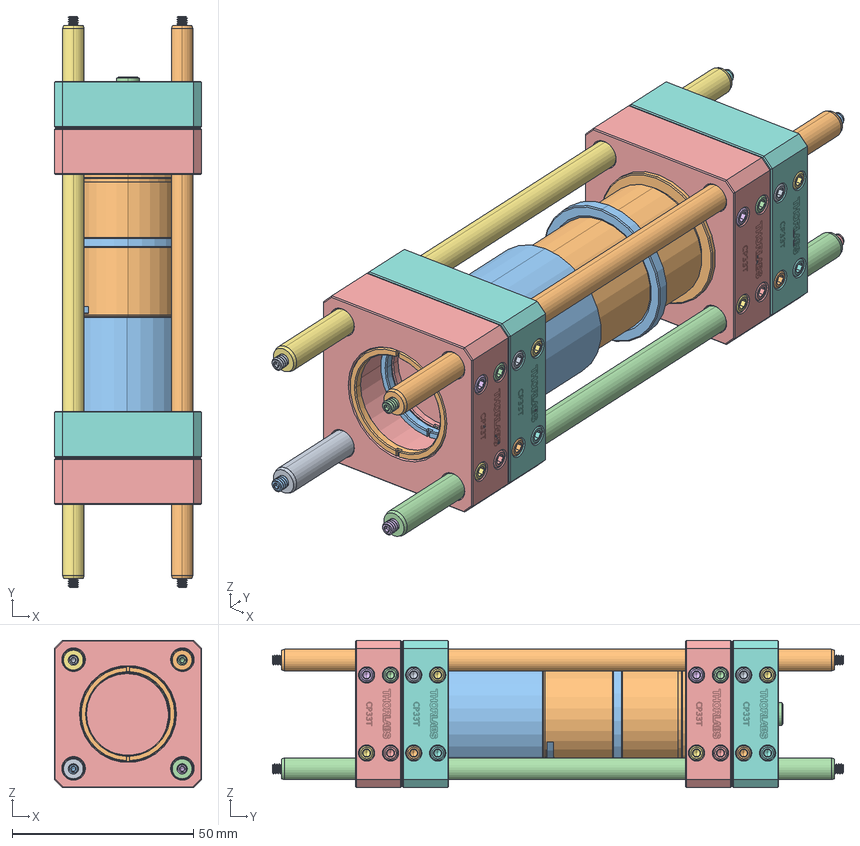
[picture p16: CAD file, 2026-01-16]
Assembly/Assembly.FCStd
40.6 x 157.5 x 40.6 mm
0877-E0W
0877-E0W001
0877-E0W002
0877-E0W004
0877-E0W005
0877-E0W006
0877-E0W008
0877-E0W009
0877-E0W010
0877-E0W012
0877-E0W013
0877-E0W014
TTN192012-E0W033
TTN192012-E0W034
TTN192012-E0W035
TTN192012-E0W036
TTN192012-E0W037
TTN192012-E0W038
TTN192012-E0W039
TTN192012-E0W040
TTN192012-E0W041
TTN192012-E0W042
TTN192012-E0W043
TTN192012-E0W
TTN192012-E0W001
TTN192012-E0W002
TTN192012-E0W003
TTN192012-E0W004
TTN192012-E0W005
TTN192012-E0W006
TTN192012-E0W007
TTN192012-E0W008
TTN192012-E0W009
TTN192012-E0W010
TTN048857-E0W
TTN048857-E0W001
LA4148
SM1RR
SM1RR001
LA4022
SM1RR002
TTN092805-E0W
TTN092805-E0W001
TTN092805-E0W002
TTN192012-E0W011
TTN192012-E0W012
TTN192012-E0W013
TTN192012-E0W014
TTN192012-E0W015
TTN192012-E0W016
TTN192012-E0W017
TTN192012-E0W018
TTN192012-E0W019
TTN192012-E0W020
TTN192012-E0W021
TTN192012-E0W022
TTN192012-E0W023
TTN192012-E0W024
TTN192012-E0W025
TTN192012-E0W026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

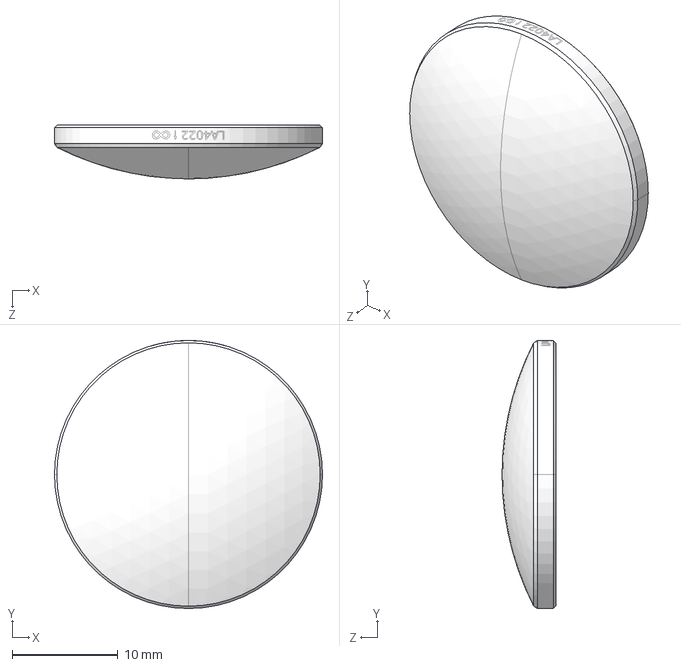
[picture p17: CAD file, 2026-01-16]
Assembly/LA4022-Step.step
25.4 x 25.4 x 5.11 mm

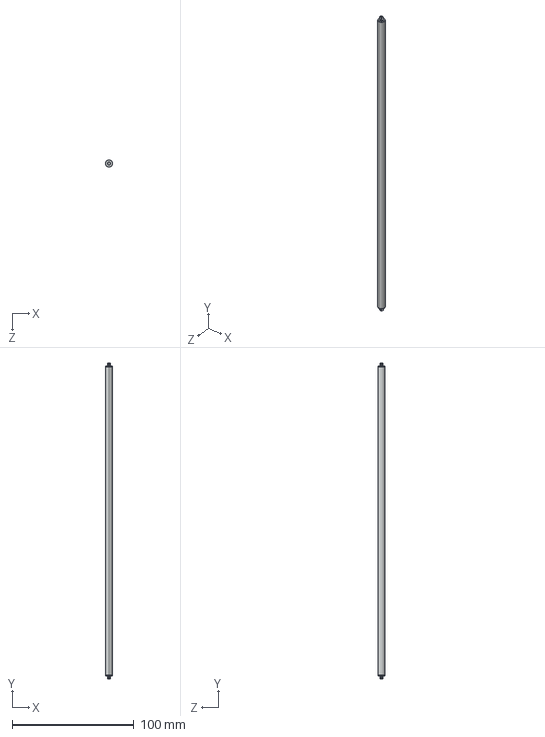
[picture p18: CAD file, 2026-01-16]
Assembly/ER10-Step.step
5.99 x 259.1 x 5.99 mm

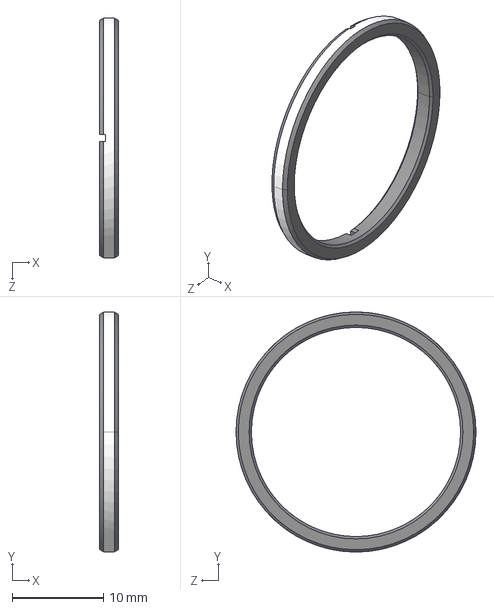
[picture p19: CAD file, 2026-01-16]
Assembly/SM1RR-Step.step
2.03 x 26.3 x 26.3 mm

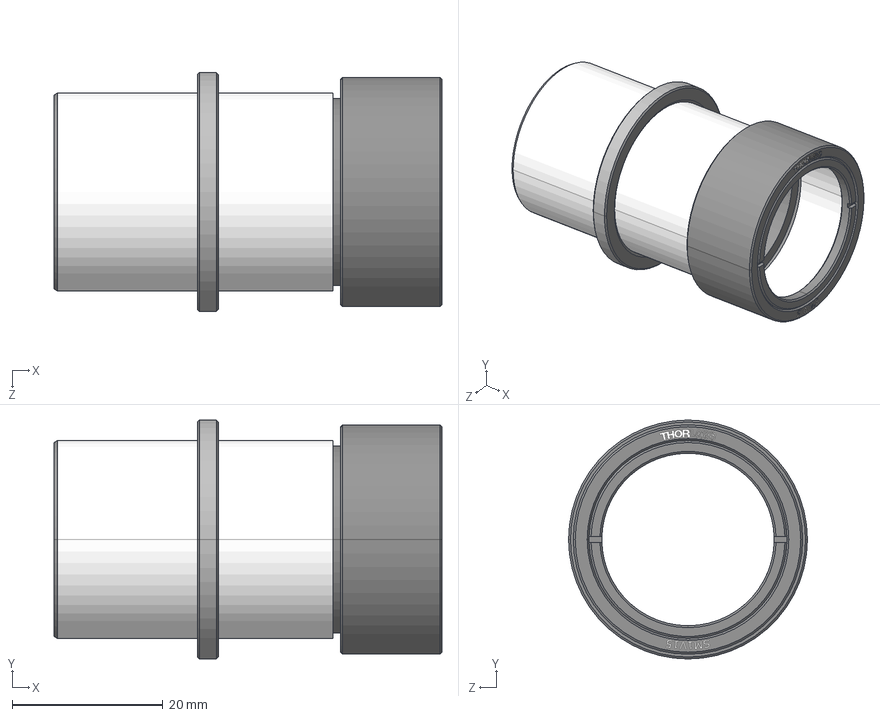
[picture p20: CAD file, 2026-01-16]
Assembly/SM1V15-Step.step
51.6 x 31.8 x 31.8 mm

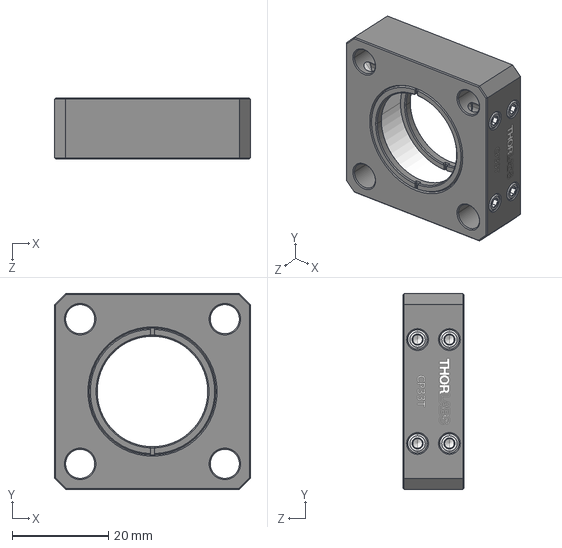
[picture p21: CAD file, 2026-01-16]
Assembly/CP33T-Step.step
40.6 x 40.6 x 12.7 mm

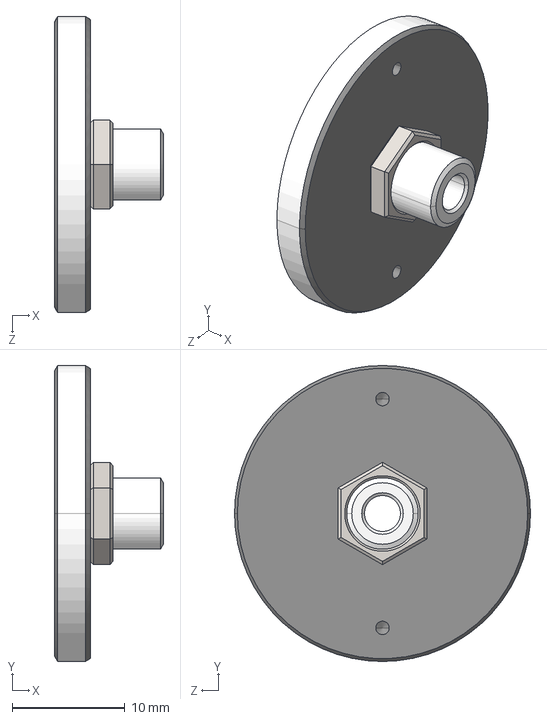
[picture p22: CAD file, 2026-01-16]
Assembly/SM1SMA-Step.step
9.65 x 26.3 x 26.3 mm

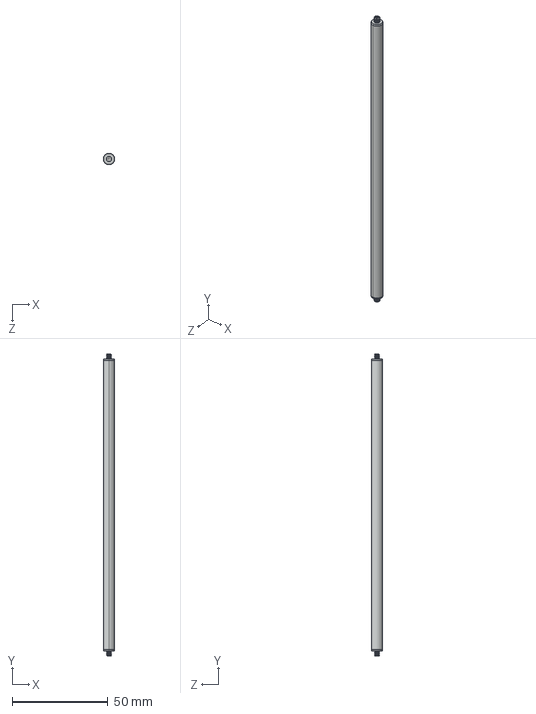
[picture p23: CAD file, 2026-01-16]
Assembly/ER6-P4-Step.step
5.99 x 157.5 x 5.99 mm

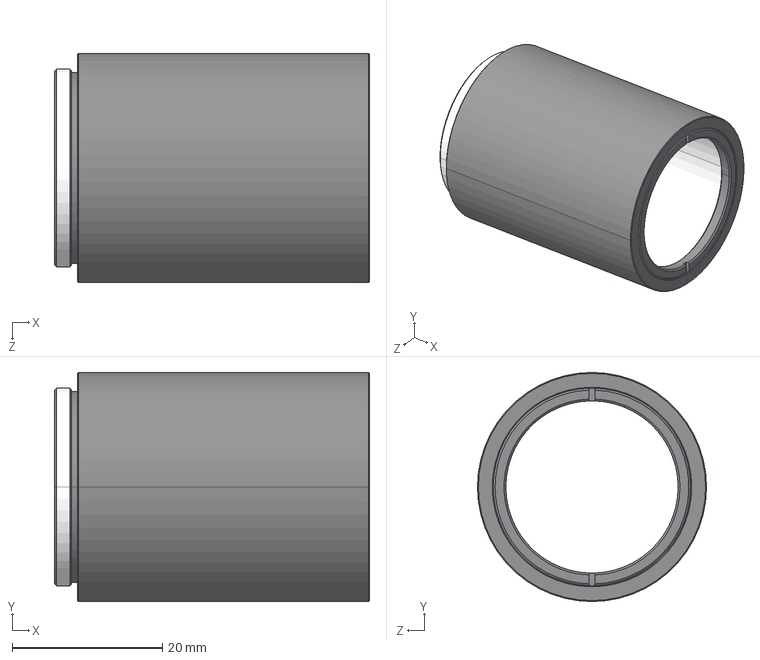
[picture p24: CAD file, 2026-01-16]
Assembly/SM1L15-Step.step
41.9 x 30.5 x 30.5 mm

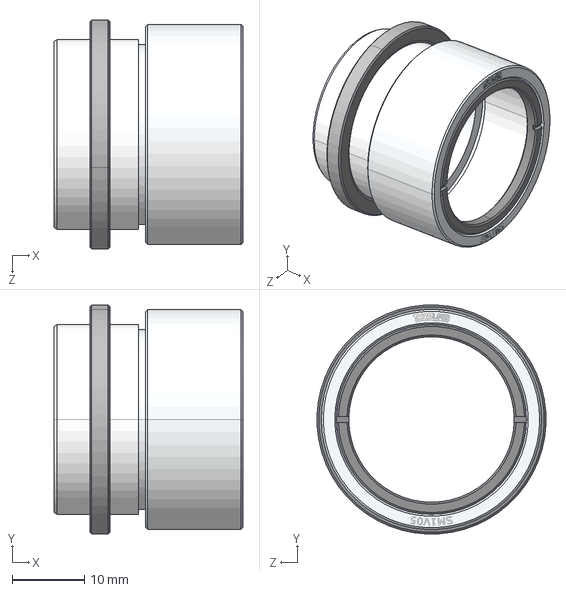
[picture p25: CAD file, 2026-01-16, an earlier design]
Assembly/Unused/SM1V05-Step.step
26.2 x 31.7 x 31.7 mm

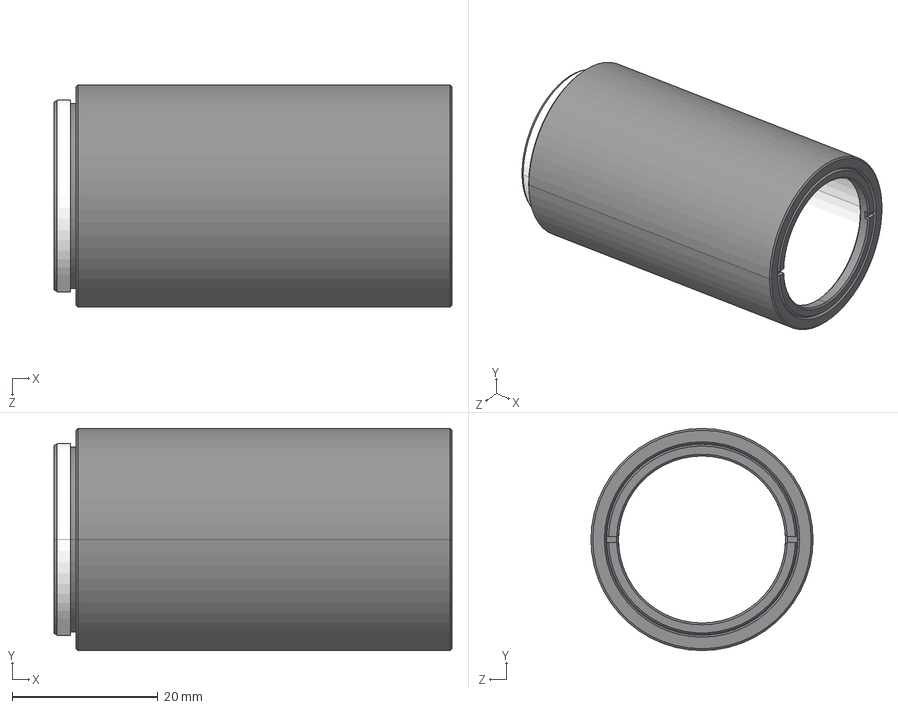
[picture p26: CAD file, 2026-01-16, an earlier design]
Assembly/Unused/SM1L20-Step.step
54.6 x 30.5 x 30.5 mm

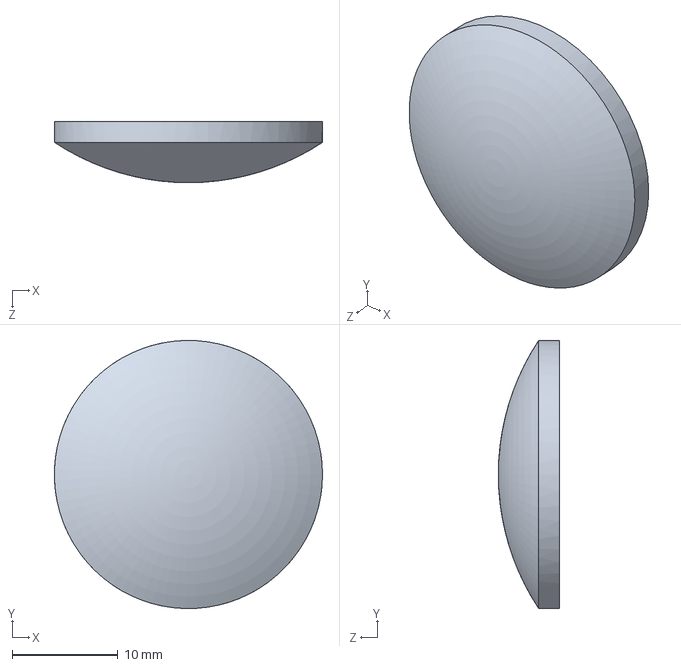
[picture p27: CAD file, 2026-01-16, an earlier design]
Assembly/Unused/LA4148-Solidworks.sldprt
25.4 x 25.4 x 5.82 mm

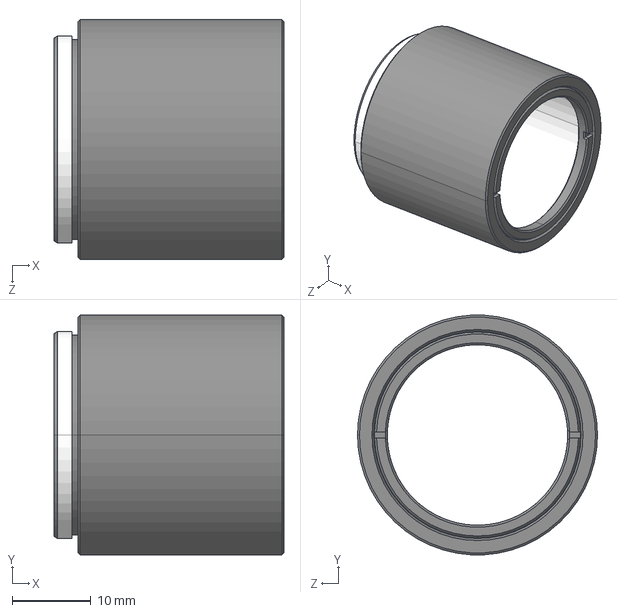
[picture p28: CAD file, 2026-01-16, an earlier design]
Assembly/Unused/SM1L10-Step.step
29.2 x 30.4 x 30.5 mm

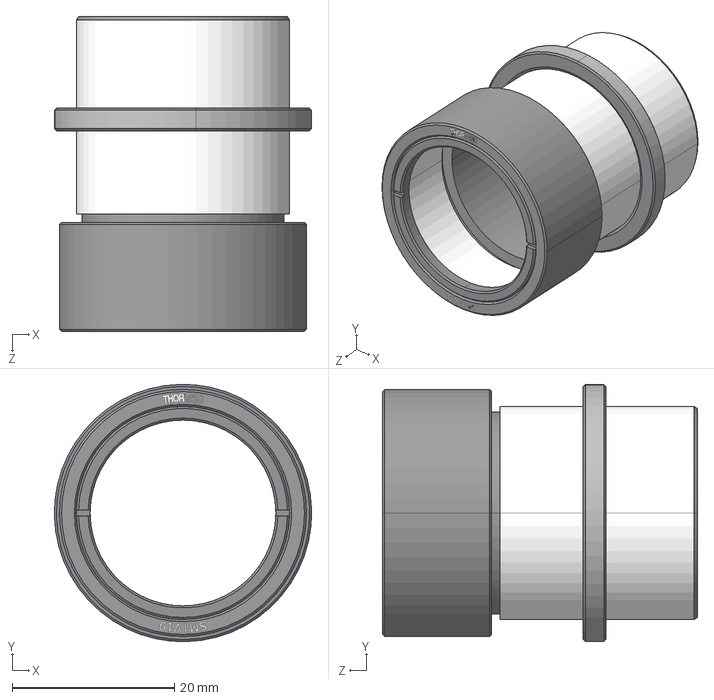
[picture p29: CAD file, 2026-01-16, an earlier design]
Assembly/Unused/SM1V10-Step.step
31.7 x 31.7 x 38.9 mm

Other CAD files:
Assembly/Unused/SM1L25-Step.step

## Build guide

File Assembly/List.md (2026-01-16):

# Parts List:
## Lenses:
    - LA4148 [](https://www.thorlabs.com/item/LA4148)
        - Diameter: 1"
        - Center Thickness: 5.8 mm
        - Focal Length: 50.2 mm
        - Material: UV-Fused-Silica
        - Coating: Uncoated
    - LA4022 [](https://www.thorlabs.com/item/LA4022)
        - Diameter: 1"
        - Center Thickness: 5.1 mm
        - Focal Length: 60 mm
        - Material: UV-Fused-Silica
        - Coating: Uncoated

## Retainers:
    - SM1RR (3-4) [](https://www.thorlabs.com/item/SM1RR)
    - Spanner Wrench for SM1 Retainers [](https://www.thorlabs.com/item/SPW602)

## Tube:
### Main Tube:
    - SM1L15 [](https://www.thorlabs.com/item/SM1L15)
        - L = 38.9 mm
### Adjustable SM1 Tube (for fine adjusting the fiber position):
    - SM1V15 [](https://www.thorlabs.com/item/SM1V15)
        - External thread length = 38.1 mm
        - Adjustment range: 2.8 mm - 36.1 mm

## Cage:
    - Cage Assembly Rod, 6" Long, Ø6 mm, 4 Pack [](https://www.thorlabs.com/item/ER6-P4)
    - SM1 30 mm Cage Plate (4) [](https://www.thorlabs.com/item/CP33T)
    - SMA Fiber Adapter Plate [](https://www.thorlabs.com/item/SM1SMA)

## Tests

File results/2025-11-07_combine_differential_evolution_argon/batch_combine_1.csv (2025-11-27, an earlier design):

lens1 | lens2 | f1_mm | f2_mm | z_l1 | z_l2 | z_fiber | total_len_mm | coupling | orientation | fiber_position_method
36-686 | 48-273 | 27.0 | 38.0 | 12.586057664888346 | 18.599961126981547 | 56.59996112698155 | 30.599961126981547 | 0.5045 | SfccfF | focal_length
36-686 | 36-687 | 27.0 | 36.0 | 12.252119791113124 | 18.354754173169624 | 54.35475417316962 | 28.354754173169617 | 0.4965 | SfccfF | focal_length
36-686 | 49-960 | 27.0 | 35.0 | 12.187815942812136 | 18.21453681739355 | 53.21453681739355 | 27.21453681739355 | 0.4825 | SfccfF | focal_length
36-686 | 36-689 | 27.0 | 35.0 | 12.4736175924333 | 18.768745295750087 | 53.76874529575009 | 27.768745295750087 | 0.442 | SfccfF | focal_length
36-686 | LA4052 | 27.0 | 35.1 | 12.460786922371495 | 18.479948253492573 | 53.579948253492574 | 27.579948253492574 | 0.415 | SfccfF | focal_length
36-686 | 49-959 | 27.0 | 30.0 | 11.731589129818058 | 17.759863135177916 | 47.75986313517792 | 21.759863135177923 | 0.378 | SfccfF | focal_length
36-686 | 36-686 | 27.0 | 27.0 | 11.262652087935562 | 17.367166485361537 | 44.36716648536154 | 18.367166485361537 | 0.334 | SfccfF | focal_length
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

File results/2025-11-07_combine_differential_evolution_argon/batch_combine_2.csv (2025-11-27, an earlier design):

lens1 | lens2 | f1_mm | f2_mm | z_l1 | z_l2 | z_fiber | total_len_mm | coupling | orientation | fiber_position_method
49-959 | 48-273 | 30.0 | 38.0 | 14.147558120103092 | 20.662055054442924 | 58.66205505444293 | 32.66205505444293 | 0.4355 | SfccfF | focal_length
49-959 | 36-687 | 30.0 | 36.0 | 13.664278416004317 | 20.168136162260478 | 56.16813616226048 | 30.16813616226048 | 0.4095 | SfccfF | focal_length
49-959 | 49-960 | 30.0 | 35.0 | 13.579029679827814 | 20.222217472451227 | 55.22221747245123 | 29.222217472451227 | 0.3845 | SfccfF | focal_length
49-959 | 36-689 | 30.0 | 35.0 | 14.040423176886472 | 20.56948824964212 | 55.56948824964212 | 29.56948824964212 | 0.378 | SfccfF | focal_length
49-959 | LA4052 | 30.0 | 35.1 | 13.95721330806257 | 20.457825937940115 | 55.55782593794012 | 29.557825937940123 | 0.3595 | SfccfF | focal_length
49-960 | 48-273 | 35.0 | 38.0 | 17.66520945262784 | 23.16625479875932 | 61.16625479875932 | 35.16625479875932 | 0.342 | SfccfF | focal_length
36-689 | 48-273 | 35.0 | 38.0 | 15.551723880731137 | 24.75389735776424 | 62.75389735776424 | 36.75389735776424 | 0.3175 | SfccfF | focal_length
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

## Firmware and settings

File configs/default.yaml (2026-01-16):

# Default configuration for raytrace-xe-flashlamp-fiber
# All physical units: mm, nm, radians (not degrees except where noted)

# Ray tracing parameters
rays:
  n_rays: 1000  # Number of rays per optimization trial
  use_vectorized: true  # Use vectorized ray tracing (10-15x faster)

# Wavelength and optical properties
optics:
  wavelength_nm: 220.0  # VUV wavelength

# Source geometry (xenon flashlamp with M23 cooling jacket)
source:
  arc_diameter_mm: 3.0                     # Arc source diameter
  lamp_window_diameter_mm: 14.3            # Lamp window diameter (at 8.7mm from arc)
  cooling_jacket_thread_diameter_mm: 23.0  # M23 thread inner diameter
  lamp_window_distance_mm: 8.7             # Distance from arc to lamp window
  window_distance_mm: 26                   # Distance from arc to cooling jacket exit
  max_angle_deg: 22.85                     # Limited by cooling jacket: atan(11.5/26.3)
  geometric_loss_factor: 0.43              # Solid angle ratio (51.4% light loss from vignetting)
  
  # Legacy field for backwards compatibility
  # window_diameter_mm: 14.3                 # Deprecated: use lamp_window_diameter_mm

# Fiber parameters
fiber:
  core_diameter_mm: 1.0  # 1000 micron core
  numerical_aperture: 0.22

# Medium properties (air, argon, or helium)
medium:
  type: air               # Options: 'air', 'argon', 'helium'
  pressure_atm: 1.0       # Atmospheric pressure
  temperature_k: 293.15   # Room temperature (20°C)
  humidity_fraction: 0.01 # Relative humidity (1%)

# Optimization settings
optimization:
  method: powell          # Options: 'powell', 'grid', 'nelder_mead', 'differential_evolution', 'dual_annealing', 'bayesian'
  
  # Powell-specific settings
  powell:
    maxiter: 1000
    ftol: 0.0001
  
  # Grid search settings
  grid:
    z_l1_min: 10.0
    z_l1_max: 30.0
    z_l1_steps: 5
    z_l2_min: 20.0
    z_l2_max: 40.0
    z_l2_steps: 5
    z_fiber_min: 30.0
    z_fiber_max: 50.0
    z_fiber_steps: 5
  
  # Differential evolution settings
  differential_evolution:
    maxiter: 100
    popsize: 15
    
  # Dual annealing settings
  dual_annealing:
    maxiter: 1000
    
  # Bayesian optimization settings
  bayesian:
    n_calls: 100
    n_initial_points: 10

# Output settings
output:
  results_dir: results
  plots_dir: plots
  log_dir: logs
  save_plots: true
  save_csv: true
  plot_style: '2d'  # Options: '2d', '3d', 'both'
  orientation: 'SfccfF'  # Options: 'ScffcF', 'SfccfF', 'both'

# Database settings
database:
  enabled: true  # Enable SQLite database for storing results
  path: ./results/optimization.db  # Path to database file

# Tolerance analysis settings
tolerance:
  z_range_mm: 1.0       # Range of z-displacement to test (±mm from optimal)
  n_samples: 21         # Number of displacement samples (should be odd)
  n_rays: 5000          # Rays per tolerance test (higher = more accurate)
  test_lateral: true   # Test x/y lateral displacements (future feature)
  test_tilt: true      # Test angular tilts (future feature)

# Batch tolerance analysis settings (for tolerance batch mode)
batch_tolerance:
  results_file: results/2025-11-19_combine_differential_evolution_argon/results_combine_2025-11-19_combine_differential_evolution_argon.csv                  # Path to optimization results CSV (null = required on CLI)
  coupling_threshold: 0.25            # Minimum coupling efficiency to include in analysis

# Analysis settings (for analyze mode - re-optimize high-coupling results)
analyze:
  n_rays: 5000          # Number of rays for re-optimization
  coupling_threshold: 0.25  # Minimum coupling to analyze
  results_file: results/2025-11-19_combine_differential_evolution_argon/results_combine_2025-11-19_combine_differential_evolution_argon.csv    # Path to results CSV file (null = required on CLI)
  methods:              # Optimization methods to test on each combination
    - differential_evolution
    - dual_annealing
    - nelder_mead
    - powell
    - grid_search
    - bayesian

# Wavelength analysis settings (test fixed geometry across wavelengths)
wavelength:
  wl_start: 150         # Starting wavelength (nm)
  wl_end: 300           # Ending wavelength (nm)
  wl_step: 10           # Wavelength step (nm)
  n_rays: 5000          # Rays per wavelength test (higher = more accurate)
  results_file: results/analyze_2025-11-19_coupling_0_25_argon/results_analyze_combined_analyze_2025-11-19_coupling_0_25_argon.csv    # Path to results CSV file (null = required on CLI)
  methods:              # Optimization methods for calibration at 200nm
    - differential_evolution
    - dual_annealing
    - nelder_mead
    - powell
    - grid_search
    - bayesian
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

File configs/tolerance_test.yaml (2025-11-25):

# Tolerance analysis configuration profile
# High-resolution tolerance testing with wider range

# Ray tracing parameters
rays:
  n_rays: 5000  # High ray count for accuracy
  use_vectorized: true

# Optimization settings - use fast Powell for baseline
optimization:
  method: differential_evolution

# Tolerance analysis settings
tolerance:
  z_range_mm: 1.0       # Wide range: ±1.0mm displacement
  n_samples: 41         # High resolution: 41 samples
  n_rays: 5000          # Many rays for accurate tolerance measurement
  test_lateral: true
  test_tilt: true

# Batch tolerance mode settings (optional - for batch analysis)
# To use batch mode:
#   python raytrace.py tolerance --results-file results/2025-11-07_combine_powell_argon/batch_combine_1.csv --coupling-threshold 0.35 --config configs/tolerance_test.yaml
batch_tolerance:
  results_file: results/2025-11-19_combine_differential_evolution_argon/results_combine_2025-11-19_combine_differential_evolution_argon.csv                  # Path to optimization results CSV (null = required on CLI)
  coupling_threshold: 0.25  # Minimum coupling to include in tolerance analysis

# Medium - use air for realistic conditions
medium:
  type: argon
  pressure_atm: 1.0
  temperature_k: 293.15
  humidity_fraction: 0.01

# Output settings
output:
  results_dir: results
  plots_dir: plots
  log_dir: logs
  save_plots: true
  save_csv: true

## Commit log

2025-10-01 final preps and fixes for running script
    [ThorLabs_Lenses.csv]
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2025-10-06 Select run Oct 1
    [two_lens_coupling_summary.csv]
2025-10-06 Knock knock. Who's there? Edmund. Edmund who? Edmund Optics.
    [Combined_Lenses.csv, Edmund-Optics_Lenses.csv, Edmund-Optics_Lenses.xlsx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]
2025-10-13 Major/minor bug fixes
    [batch_select_1.csv, batch_select_10.csv, batch_select_2.csv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]
2025-10-13 13 oct run
    [batch_select_1.csv, batch_select_10.csv, batch_select_2.csv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]
2025-10-14 Removed old faulty results
    [two_lens_coupling_summary.csv]
2025-10-15 Powell optimizer run
    [batch_select_1.csv, batch_select_10.csv, batch_select_2.csv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]
2025-10-15 Differential evolution run
    [batch_select_1.csv, batch_select_10.csv, batch_select_2.csv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]
2025-10-16 Add edge thickness support and fix bounds for small focal length lenses
2025-10-16 Powell run
    [batch_select_1.csv, batch_select_10.csv, batch_select_2.csv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]
2025-10-17 Attenuation due to medium Minschaner formula, HiTRAN database
    [36-681+36-683.csv, 36-681+48-024.csv, 36-681+84-277.csv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]
2025-10-17 Tests with attenuation
    [36-681+36-683.csv, 36-681+48-024.csv, 36-681+84-277.csv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]
2025-10-18 Wavelength analysis added
    [36-681+36-683_wavelength.csv, 36-681+84-277_wavelength.csv, 36-681+LA4002_wavelength.csv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]
2025-10-18 Extended l1 and l2 candidates
    [l1_candidates_ext.csv, l2_candidates_ext.csv]
2025-10-19 New run results; removed old ones
    [36-681+36-681.csv, 36-681+36-681_wavelength.csv, 36-681+36-683.csv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]
2025-10-20 Wavelength analysis data and plots
    [36-681+36-681_air_wavelength.csv, 36-681+36-681_argon_wavelength.csv, 36-681+36-681_wavelength.csv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]
2025-10-20 Wavelength analysis with fixed (200nm) config
    [36-681+36-681_air_wavelength.csv, 36-681+36-681_argon_wavelength.csv, 36-681+36-683_air_wavelength.csv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]
2025-10-21 lens overlap bug fixed
2025-10-22 new argon results
    [36-681+36-681.csv, 36-681+36-681_air_wavelength.csv, 36-681+36-681_argon_wavelength.csv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]
2025-10-26 Deleted old data, added new wavelength analysis air data
    [36-681+36-681.csv, 36-681+36-681_air_wavelength.csv, 36-681+36-681_argon_wavelength.csv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]
2025-10-26 Wavelength analysis plots (Moved air medium results to 2025-10-21 for convenience)
    [36-681+36-682_air_wavelength.csv, 36-681+48-024_air_wavelength.csv, 36-681+84-277_air_wavelength.csv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]
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2025-11-04 Refactor: rename 'Monte Carlo' to 'Stratified Sampling' for accuracy
    - Rename old-files/raytrace_monte-carlo.* to raytrace_stratified.*
    - Add comprehensive docstring to sample_rays() clarifying stratified sampling approach
    - Update README.md to reference new filenames and clarify sampling method
    - Add explanatory note in renamed notebook about the terminology change
    The ray tracing uses stratified quasi-random sampling (deterministic angular
    positions, random radial positions), not pure Monte Carlo sampling.
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2025-11-04 Add vectorized ray tracing for 10-15x performance improvement
    Implement NumPy-based vectorized ray tracing to replace serial ray-by-ray
    processing, achieving 10-15x speedup across all optimization algorithms.
    Key changes:
    - Add scripts/raytrace_helpers_vectorized.py with batch processing functions
    - Update all 6 optimization algorithms to use vectorized tracing by default
    - Add USE_VECTORIZED_TRACING configuration option (enabled by default)
    - Include test_vectorization.py for performance validation and correctness
    - Update README.md with performance benchmarks and usage instructions
    Performance improvements:
    - 1000 rays: 12ms vs 120ms (10.9x faster)
    - 5000 rays: 3ms vs 45ms (13.9x faster)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
    [default.yaml]
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2025-11-04 Fix database integration bugs found during integration testing
    - Initialize database in main() when USE_DATABASE is enabled
    - Pass db and alpha parameters through entire call chain (raytrace.py → runner.py → data_io.py)
    - Add run metadata insertion in write_results() before storing results
    - Fix method name extraction to handle both 'optimizer' and 'method' args
    - Correct parameter order in insert_run() call to match function signature
2025-11-04 Add tolerance analysis feature for manufacturing sensitivity testing
    - Created scripts/tolerance_analysis.py with analyze_tolerance() function
    - Tests longitudinal (z-axis) positioning sensitivity for L1 and L2 lenses
    - Calculates max coupling drop, worst-case displacement, RMS drop
    - Identifies tolerance for 1% coupling degradation
    - Compares per-lens sensitivity to determine which requires tighter tolerance
    - Added plot_tolerance_results() to scripts/visualizers.py
    - Generates side-by-side plots of L1 and L2 sensitivity curves
    - Shows baseline, 1% drop threshold, worst case, and tolerance range
    - Saves high-resolution PNG plots to plots/{run_id}/
    - Added tolerance command t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
2025-11-04 Add YAML config support for tolerance analysis parameters
    - Add tolerance section to default.yaml with z_range, n_samples, n_rays
    - Create tolerance_test.yaml profile for high-resolution tolerance studies
    - Add get_tolerance_params() method to ConfigLoader for extracting tolerance settings
    - Integrate config loading into tolerance mode with CLI argument override support
    - Separate tolerance n_rays from optimization n_rays for independent control
    [default.yaml, tolerance_test.yaml]
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2025-11-05 Bug fixes for lens orientation, 2d plots, default configs
    [default.yaml]
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2025-11-06 Fix fiber positioning bug: replace hardcoded paraxial focal length with ray-traced optimal position
    [default.yaml]
2025-11-06 Fix IndexError when using same lens twice in particular_combo
    The function was creating nested loops and trying to access combos[1], which fails when both lenses are identical (only 1 combo created instead of 4). Replaced with direct assignment of the requested combination.
2025-11-06 Add hybrid fiber positioning to optimize performance while maintaining accuracy
    Implements smart fiber positioning that uses fast paraxial approximation (z_fiber = z_l2 + f2) for well-behaved systems (coupling >= 5% OR length < 65mm), but automatically switches to full optimization search for problematic configurations. Applied consistently across all optimization methods (Powell, Nelder-Mead, differential_evolution, dual_annealing, grid_search, and Bayesian).
2025-11-06 Revert "Fix fiber positioning bug: replace hardcoded paraxial focal length with ray-traced optimal position"
2025-11-06 Config upgrade + Nov 5 run data
    [36-686+84-278.csv, 36-686+84-278_air_wavelength.csv, 36-686+84-278_argon_wavelength.csv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]
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2025-11-07 Add lens catalog browsing feature to web dashboard
    - Add 4 new API endpoints: /api/lenses, /api/lenses/<id>, /api/lenses/<id>/results, /api/lenses/stats
    - Add lens catalog tab with filtering by type, vendor, diameter, focal length, and search
    - Add lens detail modal showing complete specifications
    - Add integration to view optimization results for each lens
    - Fix parameter handling for LensDatabase.get_all_lenses() to apply sorting and limiting in Python
    - Support browsing all 202 lenses with comprehensive search and filter capabilities
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2025-11-07 Add lens import and processing utilities
    - Add add_lenses_from_csv.py for importing lens data from CSV files
    - Add import_lenses_to_db.py for bulk lens database imports
    - Add process_condenser_lenses.py for processing Edmund Optics condenser lens data
    - Add CONDENSER_LENSES_README.md documenting condenser lens import process
    - Add Edmund-Optics_condenser-lenses.csv with 46 condenser lenses
    - Support importing Plano-Convex, Bi-Convex, and Aspheric lenses with full specifications
    [Edmund-Optics_condenser-lenses.csv]
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2025-11-07 Add database integration to data I/O layer
    - Add fetch_lens_data_from_db() to query lenses from database with filters
    - Update fetch_lens_data() to support both CSV and database modes
    - Add use_database parameter to switch between CSV and database sources
    - Fix batch mode issue where lens data was not properly passed
    - Add database query methods: fetch_best_results(), fetch_results_by_lens()
    - Ensure lens dictionaries include 'lens_type' field for compatibility
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2025-11-08 Enhance optimization with intelligent fiber position evaluation
    - Add fiber_position_optimizer module to compare focal-based vs ray-based positioning
    - Integrate fiber position evaluation into all optimization methods
    - Automatically select best fiber position method for each configuration
    - Track chosen method in results database for analysis
    - Improve physical collision detection with surface sag calculations to prevent lens overlap
2025-11-08 Update raytracing helpers and visualizers for improved lens handling
    - Enhance vectorized raytracing to support aspheric lenses
    - Update visualization routines to properly render new lens types
    - Improve error handling and edge cases in raytracing
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2025-11-10 Nov 7 optimization runs and analysis
    ..
    wavelength-analysis-plots ylim fixed
    [36-686+36-687.csv, 36-686+36-687_air_wavelength.csv, 36-686+36-687_argon_wavelength.csv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]
2025-11-10 Tolerance analysis
    [tolerance_L1_36-686+36-687.csv, tolerance_L1_36-686+36-689.csv, tolerance_L1_36-686+36-690.csv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]
2025-11-10 Add individual tolerance plots to batch tolerance analysis mode
    Previously, batch tolerance mode only generated CSV data files and a single
    batch comparison plot. Now generates individual tolerance curve plots for
    each lens pair, showing L1 and L2 position sensitivity with tolerance zones.
    [tolerance_L1_36-686+36-687.csv, tolerance_L1_36-686+36-689.csv, tolerance_L1_36-686+36-690.csv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]
2025-11-10 Removed old results
    [36-681+36-681.csv, 36-681+36-681_argon_wavelength.csv, 36-681+36-682.csv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]
2025-11-10 New run (medium air)
    [36-686+36-687.csv, 36-686+36-687_air_wavelength.csv, 36-686+36-689.csv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]
2025-11-15 Updated wavelength-analysis and debugged codes
    [36-686+36-687_air_wavelength.csv, 36-686+36-687_argon_wavelength.csv, 36-686+36-689_air_wavelength.csv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]
2025-11-15 Fixed raytracing plots
    Replaced polylines with segment-by-segment line drawings to visualize
    refraction within lenses
    [results_2025-11-10-23:14:21_36-686+48-273.csv, results_2025-11-10-23:18:20_36-686+48-273.csv, results_2025-11-10-23:19:22_36-686+48-273.csv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]
2025-11-18 Cooling jacket geometry update
    [results_2025-11-10-23:14:21_36-686+48-273.csv, results_2025-11-10-23:18:20_36-686+48-273.csv, results_2025-11-10-23:19:22_36-686+48-273.csv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]
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2025-11-19 Optimized fiber positioning for coupling<0.05 and segment-by-segment ray plots
    [batch_combine_1.csv, batch_combine_2.csv, batch_combine_3.csv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]
2025-11-19 Biconvex lens drawing fix
    [results_2025-11-18-20:40:43_36-686+22-842.csv, results_2025-11-18-20:42:32_22-842+23-813.csv, results_2025-11-18-20:46:43_36-686+22-842.csv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]
2025-11-19 Cleaning run results
    [batch_combine_1.csv, batch_combine_2.csv, batch_combine_3.csv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]
2025-11-19 Paraxial approx (not verified yet)
    [batch_combine_1.csv, batch_combine_2.csv, batch_combine_3.csv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]
2025-11-25 Combine mode results new
    [48-274+LA4464.csv, 48-274+LA4464_air_wavelength.csv, 48-274+LA4464_argon_wavelength.csv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]
2025-11-25 Major bugfix: Wavelength analysis
    Calibrated refractive index for each wavelength during wavelength
    analysis. Resulted in peak coupling at target wavelength and lower
    coupling due to changed n value and chromatic abberation
    as wavelength changes in both side.
    [36-686+36-687_air_wavelength.csv, 36-686+36-689_air_wavelength.csv, 36-686+48-273_air_wavelength.csv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]
2025-11-27 System length fixed + Manual result fixes
    [36-686+36-687.csv, 36-686+36-687_air_wavelength.csv, 36-686+36-687_argon_wavelength.csv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]
2026-01-15 Update 2026-01-14 11:04
    [batch_combine_1.csv, batch_combine_10.csv, batch_combine_11.csv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]
2026-01-16 Optics Assembly
    [Assembly.FCStd, CP33T-Step.step, ER10-Step.step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]
2026-01-16 New runs
    [36-690+LA4725.csv, 48-274+48-274.csv, 48-274+48-275.csv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]
2026-01-22 Runs for documentation update
    [LA4148+LA4022_air_wavelength.csv, LA4148+LA4022_argon_wavelength.csv, results_2026-01-21-17:15:14_LA4148+LA4022.csv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]
